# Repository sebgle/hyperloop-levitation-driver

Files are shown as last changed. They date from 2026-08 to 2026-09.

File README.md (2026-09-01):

# Hyperloop Levitation Coil Driver

A two-channel H-bridge driver for the levitation coils on a hyperloop pod. It takes PWM from the
pod's control computer and switches 60 V into two coils at up to 30 A each, roughly 1.8 kW per
coil. Two boards drive the pod's four coils.

Design work for the levitation subsystem of a student hyperloop pod. The levitation team set the
requirements. The schematic, board layout, documentation and verification scripts are mine. This
repository holds the KiCad 10 project along with the design notes, the reviews, and the scripts
that check the layout.

**Status: schematic done and verified. Placement done. Routing under way.**

## Requirements

| | |
|---|---|
| Bus | 60 V max, battery fed |
| Current | 30 A per coil by design. The team's stated minimum is 60 A across all four |
| Coil | About 2 Ω and 10 mH, unmeasured |
| PWM | 16 kHz now, 32 kHz ceiling |
| Control | PID runs on a separate MCU. This board takes PWM and a shutdown line |
| Grounding | Coils float. Only common point is the motor controller negatives |
| Rails | Pod supplies 12 V, 5 V and 3.3 V |

## The board

| | |
|---|---|
| Size | 160 × 140 mm, 4 layers, 2 oz outer / 1 oz inner |
| Parts | 184 footprints, 99 nets, 492 pads |
| FETs | 8 × IRF100B201, 100 V, 4.2 mΩ, TO-220 on a shared heatsink |
| Gate drive | 4 × IR2184, bootstrap high side |
| Sensing | 0.5 mΩ shunt in line with each coil, INA240A2 amplifier |
| Protection | ±45 A window comparator into a latch on the driver shutdown pin |
| Bus | 6 × 470 µF, ceramics at each bridge, TVS clamp |
| Connectors | Molex 38969-0002, 50 A, takes 8 AWG |

## Design decisions

### Modulation

Four transistors form an H-bridge with the coil across the middle. Which pair is switched on
decides what the coil sees.

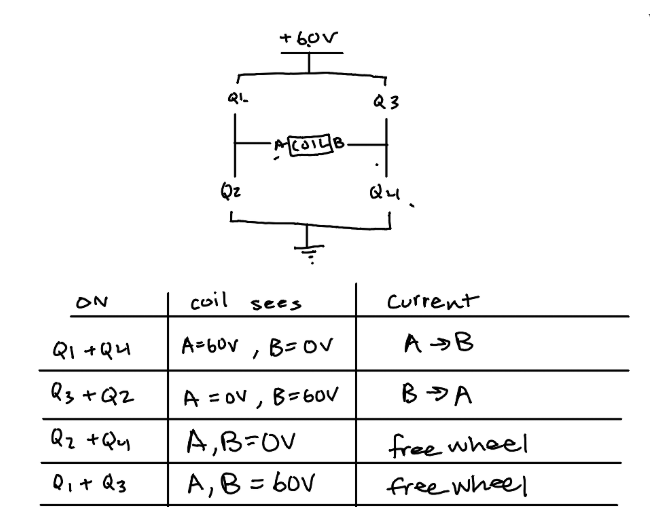
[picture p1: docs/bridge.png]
H-bridge switching states


The board cycles through these states thousands of times a second. What sets the average voltage
across the coil is which states it cycles between, and how long it holds each one.

There are two ways to pick that sequence:

```
locked antiphase   Q1+Q4 -> Q2+Q3 -> Q1+Q4 -> Q2+Q3    coil sees  +60 V, -60 V, +60 V, -60 V
unipolar           Q1+Q4 -> Q1+Q3 -> Q1+Q4 -> Q1+Q3    coil sees  +60 V,   0 V, +60 V,   0 V
```

Antiphase only uses the top two rows of the table, so the coil gets slammed between +60 V and
−60 V every cycle even when you want very little current out of it. Unipolar swaps one of those
for a freewheel row, where both ends of the coil are held at the same voltage. Nothing is
pushing the current any more, so it coasts around a loop through the two transistors and fades
slowly, the way a bike wheel spins on after you stop pedalling. A switching cycle is far too
short for it to fade much. That halves the voltage swing, and at low output the coil spends most
of each cycle coasting.

That keeps the current steadier and takes a lot of strain off the bus capacitors, which is what
decided it. A levitation coil sits near zero most of the time, so low output is its normal
operating point.

The tradeoff is that the four transistors no longer share the work evenly. Two do most of it and
run hot, two do very little and stay cool. They are arranged alternately on the heatsink so no
two hot ones sit next to each other.

### Four layers

A four-layer board costs more than a two-layer one, and the usual justification for the extra
layers, less resistance in the copper, did not apply. The power traces here are already wide
enough, and a third copper layer would save about 3 W out of 54 W.

The real reason is what sits underneath the transistors. On a four-layer board a solid ground
layer sits 0.2 mm below them instead of 1.44 mm away on the other side of the board. Current
returning through that nearby layer takes a much tighter path, which shrinks the voltage spikes
the transistors see each time they switch. The same layer shields the small measurement signals
from the 30 A being chopped a couple of centimetres away.

### Current sensing

Each coil's current is measured across a very small resistor, half a milliohm, which turns 30 A
into about 15 millivolts. An amplifier scales that up fifty times to something the rest of the
circuit can work with. The resistor sits in the wire feeding the coil rather than in the ground
return, because current in a levitation coil flows in both directions and this is the only
position that sees both. TI's application note SBOA174 covers why this amplifier suits the job.

### Overcurrent protection

If coil current passes 45 A in either direction, a comparator trips and a latch shuts the gate
drivers off and holds them off until the microcontroller clears it. Without the latch the fault
would clear itself the moment current dropped, and the board would switch on and off
repeatedly. The comparator takes 1.3 microseconds to react, which sounded far too slow until I
worked out how fast the current can actually change: the coil's inductance limits it to about
13 milliamps in that time. The genuinely fast failure is both transistors in one leg turning on
together, and the gate driver chips block that on their own.

## Checking the layout

Instead of trusting measurements written down by hand, a script reads the board file and
recalculates them. Every spacing and clearance figure quoted in the documentation comes out of
it, and it runs in about a second.

```
courtyard overlaps: 0
CH1 A   12.9 mm    CH1 B   16.7 mm
CH2 A   12.9 mm    CH2 B   16.7 mm
heatsink-shadow intrusions: none
```

The wiring was also checked against the connection list exported from the schematic, separately
from KiCad's own checker, and matched exactly on all 99 nets and 492 pads. Two rules that used
to live in a document now live in the board's rule file, so the software refuses to let me break
them: high-current nets have to be poured as wide copper areas rather than drawn as thin traces,
and the inner ground layer stays solid.

## Assumptions

Some inputs to this design were never measured, so every assumption is written down with what
happens if it turns out wrong. The full list, A1 to A16, is in `docs/09_design_sheet_rev0.md`.
Three of them matter:

- **A1**: the coil is 2 Ω. If it is really 4 Ω, the board can only push half the current and the
  high-side gate drive stops working. Nobody has put a meter on it yet.
- **A9**: 60 V is the maximum, not the normal running voltage. If it is the normal voltage, a
  full battery sits closer to 67 V and the 100 V parts get uncomfortably close to their limit.
- **A16**: the power traces are 10.7 mm wide. That figure comes from an older standard, and the
  project notes already say it should be rechecked against the current one.

## Mistakes and what they changed

**Measured the wrong thing.** Six large capacitors were supposed to fit between the two coil
connectors. Comparing the metal pads, they fit. Comparing the space each part actually needs
around it, they did not, because the connector needs far more room than its pads suggest. The
board grew from 160 × 100 to 160 × 140 mm, and I rewrote the checker to use the real keep-out
areas.

**Dropped a digit.** The board file said the copper was 0.007 mm thick instead of 0.07 mm.
Nothing inside KiCad depended on it, but it would have gone to the manufacturer, and at that
thickness the power traces would have run ten times hotter than intended.

**Trusted a number that looked deliberate.** The high-current traces were set to 3 mm wide,
which looks like a real power width. At 30 A that works out to roughly a 160 °C rise. It needed
about eight times more copper than that. The same setting had also caught ground, so all 119
ground pads inherited it.

**Reviewed in the wrong order.** Three rounds of review found 19, then 5, then 14 problems, and
about 40 % of the last round came from fixes made in the first two. Patching a design whose main
input is still unmeasured creates problems faster than review finds them, so I stopped and moved
on to layout.

## Repository layout

```
final_lev.kicad_*                KiCad project and its custom design rules
lib.pretty/                      custom connector footprint
tools/lay.py                     the layout checker
docs/00_design_log.md            running log, including the corrections
docs/01_reference_library.md     every datasheet and app note used, each one checked
docs/09_design_sheet_rev0.md     component values and the assumption list
docs/16_adversarial_review.md    38 review findings across three rounds
docs/18_firmware_interface.md    what the control microcontroller has to send
docs/20_layout_phase.md          placement and the verified clearances
docs/21_stackup_and_layers.md    layer stackup and routing order
```

## Not done

- Routing. The inner ground layer is poured, nothing else is.
- The coil has never been measured. Once it is, several numbers have to be redone together,
  because they all depend on it: ripple, transistor heating, heatsink size, gate drive supply
  and trip timing.
- Some heat calculations in `docs/09` were done under the older switching scheme.
- The bus fault detector is specified and not designed.
- `docs/09` still lists an older set of current-sense parts. The schematic is right and that
  document is stale.

## Running it

KiCad 10 on Windows. The scripts are Python 3, standard library only. From the project root:

```powershell
py tools\lay.py
```

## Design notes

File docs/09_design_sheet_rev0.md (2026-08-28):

# Design Sheet Rev 0 — Values to Draw Tonight

Levitation coil drive stage · Sebastian · 2026-08-11
**Status: provisional. Every assumption is registered in §2 with a change path.**

---

## 1. Decisions locked for this revision

| Decision | Choice | Why this one |
|---|---|---|
| **Topology** | Full H-bridge per yoke | Bidirectional confirmed (EDD Fig. 3, −16 A to +12 A) |
| **Board** | **One 2-channel board**, build two | Subset that works either way; halves bus current to 60 A; smaller layout is achievable tonight |
| **Design current** | 30 A/yoke, 15 A/coil | EDD peak, safe upper bound |
| **Design PWM** | 32 kHz (thermal worst case) | Their stated ceiling |
| **Modulation** | **Hardware-agnostic — see §3.1** | Assumption eliminated, not logged |

---

## 2. Assumption register

**This is the important artifact.** Put a copy in the schematic as a text block so it travels
with the design instead of living in your head.

| # | Assumption | Value used | Basis | Confidence | If wrong → | Change cost |
|---|---|---|---|---|---|---|
| A1 | Coil resistance | 2 Ω/coil, **1 Ω/yoke** | EDD §2.2, confirmed by independent geometry calc (250 t × 18 AWG ⇒ 1.6–2.1 Ω) | **High** | If 4 Ω: peak current halves, duty doubles to 100 %, bootstrap breaks | Rework gate drive. **Measure this first.** |
| A2 | Coil inductance | 10 mH/coil, k = 0.85, **L_yoke = 9.25 mH** | Chat recollection + my magnetic-circuit estimate (10–13 mH) | **Low** | Bus energy 2.1–5.9 J | **Nothing** — §3.2 removes the dependency |
| A3 | Modulation scheme | Unknown | — | — | — | **Nothing** — §3.1 removes the dependency |
| A4 | Logic level | 3.3 V or 5 V | Unknown | — | — | **Nothing** — §3.3 removes the dependency |
| A5 | Peak duration | **Continuous** | Deliberately conservative; EDD implies seconds | Conservative | Over-designed heatsink | None — just oversized |
| A6 | Ambient temperature | **40 °C** | Standard assumption, nobody has stated it | **Low** | Heatsink resizes linearly | Swap heatsink. Mechanical only. |
| A7 | Aux rails | Board generates its own 12 V and 3.3 V from the 60 V bus | Nobody has said the pod supplies them | Medium | If pod supplies them, DNF the regulator | **DNF one part** |
| A8 | 30 A/yoke is real | Design to 30 A | Safe upper bound whether real or inherited | Conservative | Over-designed | None |
| A9 | Bus voltage | 60 V **max** (not nominal) | EDD §2.1 states "Input Voltage (Max)" | High | If nominal, top-of-charge ~67 V → 100 V FETs get tight | Re-check FET margin |
| A10 | Board outline | **160 × 140 mm** — grew from 160 × 100 (Eurocard) on 2026-08-21 | Decided 2026-08-14 as 160 × 100, no upstream constraint stated; set by the 8× TO-220 row (~120 mm) and the §4.2 heatsink estimate (~150 × 100 mm). Grew to 140 mm tall because the six Ø16 × 31.5 mm bulk cans did not fit between the coil connectors — `20_layout_phase.md` §20.1 | Decision, not measurement | Outline changes | Re-do placement. No schematic impact. Cheapest thing here to change *before* routing, expensive after |
| A11 | Mounting | **4 × M3**, Ø3.2 mm, on a **150 × 130 mm** rectangle: H1 (105,55) H2 (255,55) H3 (105,185) H4 (255,185) | Decided 2026-08-14 as 150 × 90 when the board was 160 × 100; the holes moved with the board's growth to 160 × 140 and this entry was corrected 2026-08-24 to match the file. Nearest part 9.60 mm, edge margin 5 mm | Measured from the board, not a decision | Hole pattern moves | Move 4 holes + keepouts. Trivial before routing |
| A12 | Chassis bond | Mounting holes are `MountingHole:MountingHole_3.2mm_M3_Pad`: a **plated 3.2 mm hole with a 6.4 mm annular pad on all four copper layers**, currently carrying **no net**. Verified 2026-08-27 by reading the pad block. The 0 Ω 1206 jumper this row used to claim was specified and never drawn, and no 0 Ω part exists in the netlist, but the hole itself is a better bonding provision than that jumper would have been. The `no net found ... no pin 1 in symbol` warning on update-from-schematic is the symbol's doing: `MountingHole` has no pin, so the pad cannot inherit a net | Yokes float; the only common point is at the motor-controller negatives (`03_open_questions.md`). A bonded screw would create an unplanned 60 A return path through the pod structure, so floating is still the intended state | Medium | If chassis bonding is required | **Swap the symbol to `MountingHole_Pad` and assign the pad to GND.** Schematic edit and a re-push, no board re-spin: the copper is already there on all four layers. For a bench trial before committing, solder a wire from a GND test point to the screw (TP212 to H4 is the shortest run at 56 mm). Note for layout: because the pad has no net, every zone treats it as a foreign obstacle, which is what forces the COIL_A1 pour to keep its distance from H1 |
| A13 | Harness entry | Bus in on one short edge, coils out on the other; logic on the far long edge | Decided 2026-08-14. Follows the current path: bus → bulk → bridge → shunt → coils | Decision | Connector edges move | Re-do placement of 4 connectors and the high-current pours |
| A14 | **Modulation scheme** | **Unipolar (3-level) PWM** — leg A at D, leg B at 1−D; the two channels interleaved **90°** | Decided 2026-08-14. Bus ripple, plus linearity through zero | Decision | If locked antiphase is mandated: bus ripple 52 A rms against a ~14 A bank | **Capacitor bank moves to polymer or film.** BUS sheet respin + BOM |
| A15 | Stackup dielectrics | F.Cu→In1.Cu prepreg **0.2 mm**; core **0.97 mm**; In2.Cu→B.Cu prepreg 0.2 mm. Copper 2 oz outer / 1 oz inner, board total **1.600 mm** | Decided 2026-08-24, entered in Board Setup. Standard 1.6 mm 4-layer construction, **not** a fab’s published table — 0.97 mm is not a stocked core (0.8/0.9/1.0/1.1/1.2 are), it is the residue that makes the total land on 1.600. Reasoning in `21_stackup_and_layers.md` | Decision, not a quote | Only `dielectric 1` matters: loop inductance over the plane goes as μ₀·h/w, so a larger F.Cu→In1.Cu separation scales overshoot linearly (≈1.5 V per 10 mm of run per 1.24 mm of extra separation, at 30 A / 30 ns). Separately, JLCPCB’s **default inner copper on 4 layers is 0.5 oz**, not 1 oz — if 1 oz inner is not explicitly ordered, the In2.Cu parallel-copper saving falls from 9.30→6.20 W to 9.30→7.44 W | Replace all three dielectric rows with the fab’s actual stackup table at quote time. Board Setup edit only, no layout impact. Order 1 oz inner explicitly |
| A16 | HV net class sizing | `HV_POWER` track width **10.7 mm**, clearance **0.3 mm**, via 1.2 / 0.6. `GND` split out to `PWR_GND` (via 1.2 / 0.6); bootstrap split out to `HV_BOOT` (0.5 mm, via 0.8 / 0.4) | Decided 2026-08-24. 10.7 mm is the IPC-2221 external width for 30 A at 2 oz, ΔT = 20 °C — the class now states the sized width instead of 3.0 mm, which is ~160 °C at 30 A. 0.3 mm clearance is against IPC-2221B Table 6-1 at 51–100 V: coated external needs 0.13 mm, so 0.3 mm is 2.3×. The uncoated column (0.6 mm) applies only at pad openings, and the tightest 60 V pad pair on the board measures **0.635 mm** — the TO-220 lead pitch at Q1/Q2/Q202/Q203, 89 HV pads examined | Standard + measurement, not a guess | Conformal coating, operation above 3050 m, or a bus above 100 V all move the IPC column, and the 0.635 mm TO-220 gap becomes the binding number at 6 % margin | Net class values are a Board Setup edit. The 0.635 mm gap is set by the FET package and would need a different footprint |
| A17 | Shared bus section current | The bulk-to-bridge feed carries **both** channels, up to **60 A**. **Corrected 2026-08-27: the 28.0 mm figure in the previous version of this row was wrong**, because it applied the IPC-2221 *trace* formula to what is a *plane*. On In2.Cu at 1 oz that same formula demands **146 mm** of width, which is the whole board -- a result that says the formula is outside its validity, not that the board is impossible. A plane is counted in squares: 1 oz copper is 0.494 mOhm per square, the cap row at y=143 to the bridge row at y=62 is 81 mm across roughly 150 mm of width, so **0.54 squares = 0.267 mOhm**. Adding spreading resistance at the pads (0.026 mOhm across the six bulk caps in parallel, 0.165 mOhm at one FET drain pin) gives about **0.46 mOhm end to end: 27 mV and 1.65 W at 60 A**, spread over 150 x 80 mm, which is 0.14 mW/mm2 | Derived 2026-08-24, corrected 2026-08-27. Every width in the project until then was sized for 30 A as a trace, and the section before the bus splits was first sized the same way | Arithmetic, and the first version of it used the wrong model | The corridor width is **not** the constraint it was thought to be. In2.Cu carries the bus as a plane; every +60 V pad that carries current is through-hole (4 FET drains, 6 bulk caps, J101), so the plane reaches all of them down their own barrels with no vias in the power path. **In2.Cu still cannot be used for signal routing**, for the original reason: cutting it up would turn a plane back into traces | Re-derive if the stackup changes to 0.5 oz inner, where the sheet resistance doubles to 0.99 mOhm/square and the numbers above double with it |

**Three of the four blockers are removed by design in §3, not by assumption.** Only A1 and A2
really matter, and A2 is neutralised.

### A14 — why unipolar, in full

This is the assumption the capacitor bank rests on, so the reasoning is written out rather
than left implicit.

The coil is effectively a DC source to the bus — its own ripple is 0.15 A pk-pk against 30 A —
so whatever fraction of the period the bridge draws from the bus, it draws the *full* 30 A.
That fraction is what sets the bus RMS ripple, and it differs by a factor of three across the
three candidate schemes:

| Scheme | Bus draws for | AC ripple, 1 ch | 2 ch in phase | 2 ch interleaved (see note) |
|---|---|---:|---:|---:|
| Locked antiphase | the whole period, sign-reversing | 25.98 A | **51.96 A** | 30.0 A |
| Sign-magnitude | D = 0.5 | 15.00 A | 30.0 A | ≈ 0 |
| **Unipolar (3-level)** | \|2D−1\| = 0.5 | **15.00 A** | 30.0 A | **≈ 0** |

Six Rubycon ZLH cans give roughly **14 A**. Locked antiphase is off the table on that alone.

Between the other two, the deciding factor is **behaviour at zero current, not ripple** —
they are identical on ripple. HEMS force goes as (B_pm ± B_coil)², so with the magnets
carrying static weight the coil current trims about zero and crosses it routinely.
Sign-magnitude cannot cross zero continuously: the direction leg has to flip, which puts a
deadband and a discontinuity exactly at the operating point the loop lives at. Unipolar is
linear through zero — D = 0.5 means zero volts, zero coil current, and **zero bus draw**.

Unipolar also halves the coil's own ripple and doubles its frequency, because the coil sees
+V / 0 / −V at 2·f_sw.

**THE INTERLEAVE ANGLE IS 90°, NOT 180° — corrected 2026-08-14 night.** Under unipolar the
bus draws current only while Q1 and Q4 are both on, which happens **twice per carrier
period**, so the bus-ripple fundamental is at 2·f_sw. A 180° carrier shift is a full 360° of
that fundamental and cancels **nothing** — it is bit-identical to running the two channels in
phase. Verified numerically:

| | in phase | 180° | 90° |
|---|---:|---:|---:|
| ripple at D = 0.75 | 30.0 A | **30.0 A** | **0.1 A** |
| ripple at D = 0.875 | 26.0 A | 26.0 A | 15.0 A |
| bank capability | | | 14.1 A |

The 180° figure was carried over from the locked-antiphase analysis, where the ripple
fundamental *is* at f_sw and 180° genuinely cancels. It does not transfer. At 180° the bank
would have run at 2.1× its ripple rating.

Note the D = 0.875 row: even at 90° the bank is marginal at high duty. Either the duty needs
a clamp or the bank needs more cans — resolve when the coil is measured.

**Cost, stated honestly.** Dead time now distorts both legs rather than one, so there is a
small duty-dependent error near zero that firmware may need to compensate. That is a
calibration, not a topology problem. And the 90° interleave has to be real — if both
channels share a carrier with no phase offset, the bus ripple doubles to 30 A and the bank is
marginal again. **The interleave is a hard requirement of this assumption, not an
optimisation.**

**What this supersedes.** `16_adversarial_review.md` §5 recommended sign-magnitude. That was
right about locked antiphase being unaffordable and wrong to stop there — it optimised for
bus ripple alone and did not check the zero-crossing behaviour against the PM-biased
operating point. Unipolar gives the same ripple without the deadband.

**What still needs doing.** `09_design_sheet_rev0.md` §4.1 sizes the FET losses under
"Antiphase (design to this)". Those numbers need re-deriving for unipolar before the thermal
design is final — switching loss should fall, because each leg hard-switches less often.

---

## 3. Design moves that make assumptions not matter

### 3.1 Two independent PWM inputs per channel — kills the modulation-scheme blocker

Instead of building a logic block that converts PWM+DIR into gate signals, **bring one PWM
input per half-bridge straight to the connector.** Two PWM lines per yoke, plus one shared
shutdown.

The IR2184 already provides deadtime and shoot-through interlock internally, so each
half-bridge is safe driven from a single logic input. That means:

- **Sign-magnitude:** firmware PWMs one leg, holds the other static
- **Locked antiphase:** firmware drives both complementarily
- **Independent/mixed decay:** also available

All three in firmware, **zero hardware change**. The question I couldn't get answered stops
mattering. Cost: one extra signal wire per channel.

Per channel: `PWM_A`, `PWM_B`, `/SD`, `ISENSE_OUT`, `/FAULT`, `AGND`, `DGND`.

### 3.2 Slow-decay-on-fault — kills the bus energy-dump problem

At 30 A the yoke stores 4.2 J (up to 5.9 J at worst-case L). Dumped into bus capacitance with
the battery absent, the bus reaches **146–169 V** against 100 V parts. Capacitance cannot fix
this — even 1000 µF only gets you to 109–124 V.

**The fix is a rule, not a component.** On bus fault (undervoltage or overvoltage detected),
turn **both low-side FETs on** instead of tri-stating. The coil current then circulates
`coil → Q2 → Q4 → coil` and its energy dissipates in the coil's own 1 Ω:

    τ = L_yoke / (R_coil + 2·R_ds(on)) = 9.1–12.8 ms → fully decayed in 46–64 ms

**All 4.2 J stays in the coil. The bus never sees it.** Costs nothing but a comparator and a
local hold-up capacitor on the 12 V gate-drive rail so the FETs can still be driven for those
~60 ms.

This also makes A2 (inductance) irrelevant to the protection design — which is why the one
assumption I have least confidence in stops being a risk.

*This is what the original design's "let the coil freewheel rather than actively reverse"
instinct was reaching for. It just wasn't extended to the fault case.*

### 3.3 Schmitt-buffer the control inputs — kills the logic-level blocker

**74LVC2G17** (dual Schmitt buffer) on each channel's PWM inputs, supplied from the local
3.3 V rail. Inputs are 5 V-tolerant, so 3.3 V and 5 V MCUs both work with no change. Also
cleans up edges on a long noisy harness.

*Upgrade path:* if inter-board ground offset becomes a problem (I flagged it — the INA240
outputs sit on grounds carrying 30–60 A of switching current), swap to a digital isolator
(ISO7721 / Si8621). **Lay the footprint out to accept either** and you keep that option free.

### 3.4 Design thermals for the worst modulation

Antiphase switches all four FETs; sign-magnitude switches two. Size the heatsink for
antiphase at 32 kHz and you are safe under any answer. Costs a bigger heatsink, which is the
cheapest possible insurance.

---

## 4. Component values — ready to draw

### 4.1 Power stage (per channel)

| Item | Value | Note |
|---|---|---|
| Q1–Q4 | **IRF100B201** TO-220AB | 100 V, 4.2 mΩ max, Q_g 255 nC max, R_thJC 0.34 °C/W |
| Bus bulk | 2× **470 µF 100 V** electrolytic | Normal ripple; the fault case is handled by §3.2 |
| Bus ceramic | 4× **1 µF 100 V** 1210 + 4× **100 nF** 0805 | Right at the bridge, tight loop |
| Bus TVS | **5.0SMDJ70A** | V_R 70 V, V_BR 77.8–86 V. Residual clamp only |

**Losses at 30 A, 125 °C junction, R_ds(on) = 6.72 mΩ hot:**

| | Sign-magnitude | Antiphase (design to this) |
|---|---:|---:|
| Conduction, per channel | 12.1 W | 12.1 W |
| Switching @32 kHz, per switching FET | 3.70 W | 3.70 W |
| **Channel total** | 19.5 W | **26.9 W** |
| **Board total (2 ch)** | 39.0 W | **53.8 W** |
| Worst single FET | 6.73 W | 6.73 W |

### 4.2 Heatsink

    R_th(s-a) ≤ 1.35 °C/W

Derived at T_a = 40 °C, T_j = 125 °C, TIM = 1.5 °C/W (silpad), 53.8 W board, 6.73 W worst FET.

⚠️ **1.35 °C/W in natural convection needs a substantial extrusion** — roughly 150 × 100 mm
with 40 mm fins. With any forced air it becomes easy. **This is why ambient temperature and
airflow (question C20) matter** — it is the one open question that directly affects a
mechanical part you have to buy.

### 4.3 Gate drive (per channel: 2× IR2184)

| Item | Value | Basis |
|---|---|---|
| C_boot | **1 µF X7R 25 V** | Q_tot ≈ 405 nC → **0.41 V droop**. Budget is 1.5 V (11.3 V start − 9.8 V UVLO max) |
| R_boot | **1 Ω** | Gives **D_max = 94 %** at 16 kHz. At the 50 % design point this is enormous margin |
| D_boot | **ES1D** 200 V ultrafast | Must block the full bus |
| R_gate on | **10 Ω** | → I_g 0.70 A, t_sw 64 ns |
| R_gate off | **4.7 Ω** + parallel diode | Faster turn-off, protects against dv/dt-induced turn-on |
| Deadtime | IR2184 internal ~500 ns | Adequate against ~200 ns turn-off. Do not defeat it |
| VCC decoupling | 1 µF + 100 nF at each driver | |

### 4.4 Current sense (per channel)

| Item | Value | Basis |
|---|---|---|
| Shunt | **1 mΩ, 4-terminal, ≥2 W** | 0.90 W at 30 A. Use a metal-element 4-terminal part, not a 2512 thick film |
| Amp | **INA240A1** (gain 20) | 30 A → 600 mV. Full scale **±82 A**. 1 A → 20 mV |
| Reference | **1.65 V** from the 3.3 V rail | Bidirectional, centred |
| Placement | **In-line with the coil** | Only placement that sees true bidirectional coil current. This is what the INA240's PWM rejection exists for — TI SBOA174 Table 2 |
| Input filter | RC, corner ≫ control bandwidth | Set generously; tune once question B10 is answered |

### 4.5 Over-current protection (per channel)

| Item | Value | Basis |
|---|---|---|
| Threshold | **±45 A** | 30 A legitimate, 60 A ceiling |
| Comparator | **LM393** (dual = window comparator) | Trips at **2.55 V** and **0.75 V** against the 1.65 V ref |
| Latch | **74HC74** set-dominant, drives `/SD` low | ⚠️ The old BOM had no latch. Without one the fault self-clears and chatters |
| Reset | MCU line or power cycle | |

**Why LM393 is fine here** — its 1.3 µs propagation delay looked slow, so I checked it:
worst-case di/dt is (60 V + 30 V)/9.25 mH = 9730 A/s. In 1.3 µs the current rises **12.6 mA**.
The load inductance protects you. The fast fault is shoot-through, and the IR2184's interlock
handles that.

### 4.6 Aux rails

| Item | Value | Note |
|---|---|---|
| 60 V → 12 V | **LM5164** (100 V, 1 A synchronous buck) | Powers gate drivers. Needs ~100 mA |
| 12 V hold-up | **220 µF** local | **Required for §3.2** — the FETs must stay driven for ~60 ms after bus loss |
| 12 V → 3.3 V | Small LDO | INA240 supply, 1.65 V reference, Schmitt buffers |

*If the pod supplies 12 V and 3.3 V (question B17), DNF the LM5164 and feed the rails
directly. One part.*

### 4.7 Connectors — **and the answer for your lead**

| Connection | Part | Rating |
|---|---|---|
| **Yoke output**, battery in | **Molex 38969-0002** | **50 A, 600 V, 20–8 AWG**, 12.7 mm pitch, 2 position, PCB mount |
| Signals | Molex 0389220002 (the lead's part) | 20 A, 300 V, 12–26 AWG — fine for logic |

**This is the pitch to your lead:** same manufacturer, same barrier-strip style, PCB mount —
but **50 A and it accepts the 10 AWG the EDD specifies**. It satisfies the intent of the
constraint while meeting the actual requirement. The 20 A part stays on the signal side where
it is entirely appropriate.

---

## 5. For the LTspice build

Parameterise the two things you don't know, so a corrected measurement is a one-line change:

```
.param Rcoil=2      ; ohm per coil      -- A1, EDD, med-high confidence
.param Lcoil=10m    ; H per coil        -- A2, ESTIMATED, low confidence
.param kcpl=0.85    ; coupling          -- A2, ESTIMATED, low confidence
.param Vbus=60
.param Fpwm=32k
```

**Sweep, don't confirm.** Run `.step param Lcoil list 5m 10m 13m` and look at what actually
moves. That tells you how sensitive the design is — which is real information. Running one
sim at an assumed value and calling it verified is the previous revision's mistake.

Worth simulating tonight, in priority order:

1. **Bootstrap hold-up** across the duty range — confirms §4.3
2. **Slow-decay-on-fault** — force the bus open at 30 A and confirm the bus stays under 100 V
3. **Current ripple** vs. modulation scheme — antiphase ripple is much worse than
   sign-magnitude and this is where you'd see it
4. **OCP trip timing** into a shorted coil

---

## 6. When the answers land

| Answer | What changes |
|---|---|
| A1 = 4 Ω, not 2 Ω | **Significant.** Peak current halves, duty → 100 %, bootstrap needs a charge pump. Rework gate drive |
| A2 measured L | Nothing structural — §3.2 removed the dependency. Update the sim and the ripple numbers |
| A3 modulation | **Nothing** — §3.1 covers all cases |
| A4 logic level | **Nothing** — §3.3 covers both |
| A6 ambient ≠ 40 °C | Swap the heatsink. Mechanical only |
| B11 two-yoke flight | Board count only. Schematic unchanged |

**A1 is the one that hurts.** It is also the one with the highest confidence and the easiest
measurement. If you get one number from the lev team, get that one.

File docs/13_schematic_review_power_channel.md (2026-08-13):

# Schematic Review — `power_channel` sheet

Levitation coil drive stage · Sebastian · rev 1, 2026-08-13
Reviewed against `09_design_sheet_rev0.md`.

> **Rev 1 corrects rev 0's headline finding.** Rev 0 reported the LM393 as powered
> backwards. It is not. See §1 for the retraction and the root cause. Everything from
> §2 onward is unchanged.

**Method — read this first.** I did not eyeball the screenshot. I read the actual
`.kicad_sch` file, rebuilt the connection graph from the raw geometry (symbol origins,
library pin offsets, KiCad's rotation/mirror transforms, wire segments, junctions,
labels, power symbols) and extracted the netlist myself. Every claim below is a
statement about the file, not about a picture of it. Where I could not resolve
something from the file alone, I say so.

Sheet contents: **54 components** (23 C, 19 R, 4 Q, 3 D, 5 U) + 32 power symbols,
142 wires, 57 junctions, 36 labels, 2 no-connect flags, A3 paper.

---

## 0. Geometric hygiene — clean

These are the errors that normally hide in a hand-drawn sheet. The file has none of them:

| Check | Result |
|---|---|
| Wire endpoints ending in mid-air | **none** |
| Labels sitting on nothing | **none** |
| Wires crossing without a junction where one is needed | **none** |
| Wires crossing *with* an unintended junction | **none** |
| Component pins not touching anything | only U5.8 / U5.9, both correctly flagged no-connect |
| Power symbols attached to nothing | **none** |
| Duplicate / overlapping wire segments | none |

Every net resolves. That is a genuinely clean drawing job for 142 wires.

---

## 1. RETRACTED — the LM393 supply is correct

**The first issue of this document claimed U4 was powered backwards. That was wrong.
Sebastian caught it. There is no blocking error on this sheet.**

Correct netlist: **U4 pin 8 (V+) → `+5V`. U4 pin 4 (V−) → `GND`.**

### What I got wrong, and why it matters for the rest of this document

Everything here is reconstructed from raw geometry, which means it all rests on getting
KiCad's rotation matrices right. For a symbol placed at `(at x y 90)` the mapping from
library coordinates to sheet coordinates is one 2×2 matrix, and I solved for it
empirically by testing candidates against the file and keeping the one that made pins
land on wires.

I tested the wrong pair. The two candidates I compared were:

    (0, 1, 1, 0)    det = −1     ← legal
    (0, 1, −1, 0)   det = +1     ← NOT legal for an unmirrored symbol

and picked the second because it made U4's pins land on the +5 V wire and the GND symbol
while the first left them floating. That was real evidence and it pointed at a
physically impossible transform.

**The constraint I skipped:** every unmirrored symbol placement in KiCad is the default
transform `(1, 0, 0, −1)` — determinant −1, because library Y is up and sheet Y is down —
composed with a pure rotation, determinant +1. The product must have **determinant −1**.
A determinant +1 matrix is a *mirrored* placement, and the file says plainly that U4 has
no mirror. That one check eliminates my answer in a single line.

The two legal candidates for the 90° family are `(0, 1, 1, 0)` and `(0, −1, −1, 0)`. I
never tested the second, because I had it filed under 270°. It is the right one:

    90°  → (0, −1, −1, 0)        270° → (0, 1, 1, 0)

Under the correct matrix, U4 unit 3's pins land at y = 59.69 with **V+ at x = 128.27**
(the +5 V wire) and **V− at x = 143.51** (the GND symbol). Which is what the schematic
looks like on screen, which is what Sebastian said.

**The process failure, stated plainly:** I treated "which hypothesis makes more pins land
on wires" as decisive without first checking whether the hypothesis was admissible.
Landing on wires is *evidence*. The determinant is a *constraint*. Constraints get
applied first — they are free, and they delete whole branches before you start weighing
evidence.

And note the shape of the failure, because `08_honest_assessment.md` already named it:
*a design that is internally consistent and externally wrong passes every check you can
run on it.* This time it was the analysis, not the design. My reconstruction was fully
self-consistent under a transform that cannot physically exist, and it stayed
self-consistent right up until someone looked at the actual screen.

### What this retraction does and does not touch

Re-running the extraction with the corrected matrices changes the netlist in exactly one
substantive place — U4's two supply pins. Every other difference is a pin-number swap on
a symmetric two-terminal part (resistors, non-polarised capacitors), where net
*membership* is identical and only the 1/2 labelling flips. Verified by diff.

**The only polarised parts at 90° or 270° are U4 unit 3 and D2.** D2 re-checks correct:
cathode on `+60V`, anode on `GND`. But given the above, please confirm it with your eyes
rather than my arithmetic — **the cathode bar (the flat line with the little Z-ticks
on the ends) should be at the top, against the +60 V rail, with the triangle pointing up
into it.** If it looks the other way round, tell me.

Everything in §2 onward is independent of the rotation question and stands unchanged.

---

## 2. The protection chain is correct

I traced it pin by pin and it does what it is supposed to do.

**LM393 supply** — U4 pin 8 (V+) → +5V, pin 4 (V−) → GND, decoupled by C21 100 nF across
the same two rails. **Correct.**

**Threshold divider** — R14 10k (+3.3V→VTH_HI), R15 24k (VTH_HI→VTH_LO), R16 10k
(VTH_LO→GND).

    VTH_HI = 3.3 × 34/44 = 2.550 V
    VTH_LO = 3.3 × 10/44 = 0.750 V
    trip    = (2.55 − 1.65) / (20 × 1 mΩ) = ±45 A      ✓ matches §4.5

Both thresholds and the INA240's 1.65 V mid-scale derive from the *same* 3.3 V rail, so
the trip point is ratiometric — rail error cancels instead of shifting the trip. That is
a real property of the way you drew it and worth saying out loud in the writeup.

**Comparator polarity** — U4A: `+` = VTH_HI, `−` = ISNS → output pulls low when ISNS
climbs above 2.55 V. U4B: `+` = ISNS, `−` = VTH_LO → output pulls low when ISNS falls
below 0.75 V. Both open-drain outputs (pins 1, 7) tie to `FAULT_N` with R17 10k to +5 V.
Crossed inputs give you OR, not AND. **Correct.**

**Latch** — U5A: pin 4 (S̄/PRE) ← FAULT_N, pin 1 (R̄/CLR) ← RESET node, pins 2 & 3
(D, CLK) → GND, pin 5 (Q) → FAULT, **pin 6 (Q̄) → SD**. Power-on: C22 holds R̄ low,
Q = 0, Q̄ = 1, SD high, drivers enabled. Fault: S̄ low → Q = 1 (FAULT out), Q̄ = 0 →
SD low → shutdown. Set-dominant, powers up in the no-fault state. **Correct.**

**U5B tied off** — pins 10 (S̄) and 13 (R̄) to +5V, pins 11 (C) and 12 (D) to GND,
pins 8 and 9 no-connect. **Correct** — unused outputs left open, unused inputs tied,
which is the right way round.

**R19** 10k from SD to GND: if the latch loses power, SD is pulled low and the bridge
shuts down. Fail-safe in the correct direction. **Correct.**

**INA240** — IN− (1) ← R13 ← COIL_A, IN+ (8) ← R12 ← SW_A, OUT (5) → ISNS, VS (6) →
+3.3V with C20 100 nF, GND (2) → GND, REF1 (7) → GND, REF2 (3) → +3.3V. Verified against
TI SBOS662: pin 4 is "Reserved. Connect to ground or leave floating" — you tied it to
GND, which the datasheet explicitly permits. (My earlier sketch said "leave open"; both
are legal, no change needed.)

Current sign: sourcing current leaves SW_A, crosses the shunt, enters COIL_A, so
V(SW_A) > V(COIL_A) → IN+ > IN− → ISNS rises above 1.65 V. Positive coil current reads
high, which is what the +45 A threshold assumes. **Correct.**

**Bus TVS D2** — cathode on +60V, anode on GND. **Correct.** (I re-derived the 270°
rotation from scratch to check this one; it comes out right.)

**Electrolytics C9/C10** — pin 1 (+) on +60V. **Correct.**

**Bootstraps** — U1: +12V → R5 (1Ω) → D1 (ES1D, anode from R5, cathode to VB) → VB(8),
C4 1 µF across VB–SW_A. U2: identical with R8/D3/C16. Diode orientation correct in both.

**Gate loop** — R1/R2/R9/R10 10 Ω 1206 in series with each gate; R3/R4/R6/R7 10k
pulldowns, each returned to *its own* source (SW_A / GND / SW_B / GND), not to a common
node. **Correct** — this is the detail most people get wrong.

**Bridge** — Q1/Q3 drains on +60V, Q2/Q4 sources on GND, SW_A = Q1.S/Q2.D, SW_B =
Q3.S/Q4.D. Shunt R11 in series between SW_A and COIL_A; COIL_B taken directly off SW_B.
The shunt therefore carries true coil current. **Correct.**

---

## 3. Design-level findings — these are about the design, not the drawing

### 3.1 The bulk capacitors cannot carry the ripple current — quantified

This has been on the open-risk list unquantified. Here is the number.

At the 30 A design point with D ≈ 0.5:

    I_rms(bus) = I_load × √(D(1−D)) = 30 × 0.5 = 15 A RMS per channel

How that 15 A splits between the ceramics and the electrolytics, at 32 kHz:

    8 × 1 µF ceramic:        Z ≈ 1/(2π·32k·8µ)   ≈ 620 mΩ
    2 × 470 µF electrolytic: Z ≈ ESR ≈ 25 mΩ  (two 50 mΩ parts in parallel)

The electrolytics are ~25× lower impedance, so **they take essentially all of it —
roughly 14 A RMS into a pair of parts rated about 2 A RMS each.** They will run hot,
dry out, and fail. The ceramics do not rescue this: to move the split you would need
the ceramic bank below 25 mΩ at 32 kHz, which is ~190 µF of 100 V ceramic before DC-bias
derating. Not buildable.

**Options, cheapest first:**

1. **More electrolytics** — 6× 470 µF/100 V standard radial gets you to ~16 A. Six 18 mm
   cans is a lot of board area.
2. **Polymer or hybrid aluminium** — 3–4× 470 µF/100 V polymer at 3–4 A RMS each. Fewer
   parts, much lower ESR, more expensive. This is what I would do.
3. **Lower the design current** — if the real continuous number turns out well below
   30 A (still an open question with the lev team), the problem shrinks as I².

**What does *not* fix it:** interleaving the two channels 180° out of phase cancels
ripple on the *shared* bus/battery side, but each channel's local commutation loop still
circulates its own ripple through its own nearest caps. Interleaving is worth doing —
it's free in firmware — but do not size the caps on the assumption it will hold.

The schematic topology does not change either way. Add two more C_Polarized symbols now
if you want the footprints, and settle the part at procurement.

### 3.2 The over-current path does the one thing §3.2 of the design sheet forbids

`09_design_sheet_rev0.md` §3.2 is explicit: on a fault, turn **both low-side FETs on**
rather than tri-stating, so the coil dumps into its own resistance and the bus never sees
the energy.

The OCP you have drawn pulls `SD` low, which tri-states both half-bridges. That is a hard
turn-off. The coil current then freewheels through the FET body diodes into the +60 V bus:

    E = ½ · L_yoke · I²  = ½ × 9.25 mH × 45²  = 9.4 J
    into 940 µF from 60 V:  V = √(60² + 2E/C) = 153 V   against 100 V parts

**When this matters:** only if the bus is isolated at the moment of the trip — battery
disconnected, fuse open, contactor open. With the battery present it absorbs the energy
and the bus barely moves, which is the normal case.

**Why I am flagging it anyway:** an over-current is a plausible *cause* of a blown fuse.
The two conditions are correlated, not independent, so "compound failure, ignore it" is
not quite right.

**Two ways forward, pick one and log it:**

- **(a) Accept for rev0.** Log it as a known limitation: OCP hard-off is safe only with
  the bus connected. Zero cost, zero schedule impact. Defensible for a first article.
- **(b) Gate the PWM inputs instead of SD.** Route `PWM_A` / `PWM_B` through a 2-input
  AND (one 74HC08, or two 74HC1G08) with the latch's Q̄. On fault, PWM goes low → the
  IR2184 turns its **low side on** → the coil circulates through Q2 and Q4 → slow decay,
  exactly §3.2, with `SD` left high. Cost: one logic part per board and the 12 V hold-up
  cap you already specified in §4.6. This also makes the OCP path and the bus-fault path
  behave identically, which is worth something on its own.

I would take (b) if you have an hour, (a) if you do not. Either is defensible; silently
having (a) while the design sheet claims (b) is not.

### 3.3 The turn-off diode from §4.3 is missing

Design sheet §4.3 specifies **R_gate on 10 Ω, R_gate off 4.7 Ω + parallel diode**. The
schematic has a single 10 Ω resistor per gate and no turn-off path.

In an H-bridge, when one FET turns on the opposite switch node slews fast and Miller
current through C_gd of the *off* FET tries to pull its gate up. A slow, symmetric
turn-off makes that worse. The asymmetric network is cheap insurance: one small-signal
diode (BAV21 / 1N4148W) and one 4.7 Ω resistor across each 10 Ω.

Four gates × 2 parts = 8 extra parts. Either add them or delete the line from §4.3 —
right now the design sheet and the schematic disagree, and that is exactly the kind of
drift that makes a design document worthless later.

### 3.4 The shunt is the 2512 thick film the design sheet told you not to use

`R11` footprint is `R_2512_6332Metric`. §4.5 says "1 mΩ, 4-terminal, ≥2 W. Use a
metal-element 4-terminal part, **not a 2512 thick film**."

At 45 A the shunt dissipates 2.0 W. A standard 2512 is 1 W. And a thick-film 1 mΩ has a
TCR in the hundreds of ppm/°C, so the trip point walks with temperature.

This was logged as a deliberate compromise, so it is not new — but the footprint is now
committed in the file, and swapping to a 4-terminal part later is a layout change, not a
BOM change. Metal-element parts that fit a 2512-class outline exist (Vishay WSLP2512,
Bourns CSS2H-2512 — 2 W and 3 W versions, ~50 ppm/°C). If you keep 2 terminals, at least
move to a metal-element part now so only the Kelvin question stays open.

### 3.5 The INA240 input filter is not filtering anything

R12 = R13 = 10 Ω, C19 = 1 nF differential.

    f_c = 1/(2π · (R12+R13) · C19) = 1/(2π · 20 · 1n) = 7.96 MHz

That is three decades above anything on this board. It is not wrong — TI's own guidance
(SBOA174) is that the INA240 is *designed* to reject the common-mode step and that heavy
input filtering degrades the CMRR balance it depends on — but you should know that this
network is doing essentially nothing, and say so, rather than have someone assume it is
a 20 kHz filter.

If you want real filtering, put it **after** the INA240 on ISNS, where a resistor costs
you nothing in gain error.

### 3.6 No bus bleed resistor

940 µF at 60 V is **1.7 J** with no discharge path. On a hand-assembled board that people
will probe, that is a shock and short hazard that persists after power-down.

Add one resistor from +60V to GND: 22 kΩ, 0.16 W steady (use a 0.5 W or two 11 k in
series for voltage rating), discharges to under 10 V in about a minute. Cheap, and it is
the kind of thing a reviewer notices immediately.

### 3.7 Single GND

§3.1 of the design sheet lists `AGND` and `DGND` separately at the connector. The
schematic has one `GND`. For rev0 this is defensible — one net, one star point, handled
in layout — but it is a decision, so log it. The INA240 output and the comparator
thresholds both reference this ground while it carries 30–60 A of switched current.

---

## 4. Fix before you run ERC

| # | Item | Action |
|---|---|---|
| 1 | ~~U4 power reversed~~ | **Retracted — see §1. Nothing to fix.** |
| 2 | Missing footprints | `U5` (74HC74), `C19`, `C20`, `R12`, `R13` have no footprint assigned |
| 3 | Hierarchical label shapes | All 7 are `input`. `COIL_A`, `COIL_B` should be `passive` (or `bidirectional`), `ISNS` and `FAULT` should be `output`. As drawn, the parent sheet will throw "input pin not driven" on nets that are actually outputs |
| 4 | Value string consistency | `100 nF` (C2, C17) vs `100nF` (C3, C11, C21, C22, C23) — splits your BOM into two lines. Pick one |
| 5 | `R11` value `1mR` | Ambiguous in a BOM. Use `0R001` or `1m` |
| 6 | Bootstrap cap mismatch | C4 is 1210, C16 is 0805 — same function, same part. Make both 0805 |
| 7 | No voltage rating anywhere | **The most dangerous BOM omission on a 60 V board.** Add a `Voltage` field to every capacitor. C3/C11 (100 nF, 0805) on the bus need ≥100 V. C9/C10 need ≥100 V |
| 8 | Tolerance field | R14/R15/R16 set the trip point — add `Tolerance = 1%` so procurement cannot substitute 5% |
| 9 | Title block | Empty. Fill in title, rev, date, your name |
| 10 | MPN coverage | 9 of 54 parts have an MPN field |

Items 2–10 stand. Note that with the U4 finding retracted, the "power input pin not
driven" errors ERC will raise on `+5V`, `+3.3V`, `+12V`, `+60V` and `GND` are now
*purely* the expected missing-PWR_FLAG messages, with nothing hiding inside them.

**ERC messages you should expect and should NOT "fix" on this sheet:**

- *Power input pin not driven* on `+60V`, `+12V`, `+5V`, `+3.3V`, `GND` — correct. Those
  rails are generated on `AUX_RAILS`, which does not exist yet. The PWR_FLAGs belong
  there, not here. Do not sprinkle PWR_FLAGs on this sheet to silence them.
- Possible *"net has more than one name"* on the SW_B / COIL_B node. That node genuinely
  is both — half-bridge B's switch node *is* the coil B terminal, because the shunt is
  only in the A leg. Intentional.

---

## 5. Verify this one thing about the +60 V net

`#PWR01` is the `power:+12V` library symbol with its **Value** field edited to `+60V`.

In this file every power symbol's library pin is unnamed, which means KiCad takes the net
name from the Value field — so `+60V` should be a distinct net from `+12V`. The netlist I
extracted agrees: `+60V` contains only the bridge drains and the bus bank; `+12V` contains
only the two driver VCC pins.

But confirm it in KiCad rather than taking my word for it, because the failure mode is
catastrophic — if those two merged, 60 V lands on the IR2184 VCC pins. **Hover the +60 V
rail and the +12 V rail and read the net names off the status bar.** Ten seconds.

---

## 6. File hygiene — fix this before you do anything else

Your project is at `Desktop\final_lev\`. The root sheet's `Sheetfile` property reads:

    ..\..\Downloads\power_channel.kicad_sch

**Your live schematic is in your Downloads folder, outside the project.** And there are
two stale decoys sitting *inside* `final_lev\`:

| File | Symbols | Status |
|---|---|---|
| `Downloads\power_channel.kicad_sch` | 58 | **live — this is your work** |
| `final_lev\power_channel.kicad_sch` | 37 | stale (no INA240, no LM393, no 74HC74, no shunt) |
| `final_lev\copy_power_channel.kicad_sch` | 24 | older still (bridge + drivers only) |

Downloads is the folder people clean out. And the two decoys are one mis-click from being
loaded and quietly losing you a day.

**Procedure — do it in this order:**

1. Close KiCad completely (there is a `~final_lev.kicad_sch.lck` right now).
2. Move `final_lev\power_channel.kicad_sch` and `final_lev\copy_power_channel.kicad_sch`
   somewhere out of the project — an `_old\` subfolder is fine.
3. Copy `Downloads\power_channel.kicad_sch` into `final_lev\`.
4. Open `final_lev.kicad_sch`, right-click the sheet symbol → Properties → set the sheet
   file to `power_channel.kicad_sch` (no path).
5. Open the sheet and confirm you see the INA240, the LM393 and the 74HC74. If you see a
   bare H-bridge, you loaded a decoy — back out and try again.
6. Then put the whole `final_lev` folder under git, or at least next to `levpdu`.

I can run steps 2 and 3 for you once KiCad is closed — say the word.

---

## 7. Summary

**No blocking errors.** The originally-reported LM393 supply reversal was my mistake and
is retracted in §1, with the root cause written up there because the root cause is more
useful than the finding was.

What remains:

- One quantified component problem — bus electrolytic ripple current, ~7× over rating (§3.1)
- One architectural decision to make explicitly rather than by accident — OCP hard-off
  vs. slow decay (§3.2)
- Two design-sheet items that did not make it into the drawing — gate turn-off diode,
  shunt type (§3.3, §3.4)
- Four smaller design notes (§3.5–3.7)
- Nine housekeeping items before ERC (§4)

The drawing itself — 142 wires, 57 junctions, 54 parts, no dangling ends, no missing
junctions, no stray labels, no floating power symbols, every polarity correct — is clean.
The real work left on this sheet is component selection and two documented decisions, not
correction.

---

## 8. Revision history

| Rev | Date | Change |
|---|---|---|
| 0 | 2026-08-12 | First issue |
| 1 | 2026-08-13 | **§1 retracted.** LM393 supply is correct; the reported reversal was an error in my geometric reconstruction (wrong rotation matrix, determinant +1, physically inadmissible). Caught by Sebastian from the schematic on screen. Netlist re-extracted with corrected matrices; one substantive change (U4 pins 4/8), all other deltas are pin-number swaps on symmetric parts. D2 polarity re-verified. §§2–6 unaffected. |

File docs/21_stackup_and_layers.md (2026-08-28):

# 21 — Stackup: copper weight, layer count, and why

**Decision date:** 2026-08-24
**Status:** decided and recorded. **Board Setup not yet reconfigured** — see §21.6.

---

## 21.1 A stackup bug found first

The board file carried **0.007 mm** copper on F.Cu and B.Cu. `14_power_channel_closeout.md`
records the intent as "copper 0.035 → 0.07 mm (2 oz)", so this was a dropped digit, not a
decision — 0.007 mm is not a copper weight that exists. Board total read 1.474 mm; with 0.07 it
comes to exactly 1.600 mm, which is what the design was aiming at.

It affects nothing already done — KiCad does not compute ampacity, so no DRC or clearance
result depended on it — but it propagates into fab outputs, and a fabricator reading the
stackup literally could have quoted 0.2 oz. At 0.007 mm the coil pours would have dissipated
**ten times** the intended power.

**Fixed** 2026-08-24 by direct file patch (KiCad closed): F.Cu and B.Cu → 0.07 mm, board total
1.474 → 1.600 mm. Core left at 1.44 mm.

> A first attempt at this patch also changed the core to 1.46 mm, which would have made the
> total 1.62 mm. Caught in the script's own printed output and reverted in the same session.
> The lesson is the cheap one: have the script print the number it computed, not just the
> number it wrote.

### What the copper is worth

```
sheet resistance (mohm/square)        20 C     70 C     85 C
  0.007 mm  (as the file had it)     2.463    2.947    3.092
  1 oz   (0.035 mm)                  0.493    0.589    0.618
  2 oz   (0.070 mm)                  0.246    0.295    0.309
  3 oz   (0.105 mm)                  0.164    0.196    0.206
```

---

## 21.2 The copper-loss picture

Coil-path loss at 30 A, on the 10.7 mm pours already placed, 2 oz, at 85 °C:

```
CH1 shunt -> J203    91.7 mm   8.57 sq   2.65 mohm   2.38 W
CH1 SW_B  -> J203    92.0 mm   8.60 sq   2.66 mohm   2.39 W
CH2 shunt -> J204    78.0 mm   7.29 sq   2.25 mohm   2.03 W
CH2 SW_B  -> J204    95.9 mm   8.96 sq   2.77 mohm   2.49 W
                                              TOTAL   9.30 W
```

With a via-stitched second copper layer in parallel:

```
+1 oz inner  (typical 4-layer)   6.20 W    saves 3.10 W   (33%)
+2 oz inner  (heavy 4-layer)     4.65 W    saves 4.65 W   (50%)
```

### The pour width is already correct

IPC-2221 external-layer sizing for 30 A at 2 oz:

```
dT = 10 C  ->  16.4 mm
dT = 20 C  ->  10.7 mm     <-- the width actually placed
dT = 30 C  ->   8.4 mm
dT = 45 C  ->   6.6 mm
```

The placed pours are exactly the ΔT = 20 °C width. Whoever sized them did it properly, and
**the copper-loss argument therefore does not justify four layers** — 3.1 W saved on a ~54 W
board, against pours that are already right.

---

## 21.3 The argument that actually decided it

**Four layers, 1 oz inner.** Four reasons, in order of weight.

**1. Choosing four now is free; choosing two and being wrong is not.** The placement is
identical either way — nothing already done is wasted. But if a 2-layer route ends with the
bottom pour shredded under the FET row, the remedy is not a tweak, it is a reroute. That
asymmetry settles the question on its own.

**2. The stackup geometry is doing work.** A standard 1.6 mm 4-layer puts thin prepreg
(~0.2 mm) between L1 and L2, with the thick core between L2 and L3. That places the ground
plane **0.2 mm** below the FET row instead of 1.44 mm away on the far side of a 2-layer board.
Loop inductance scales with that separation. This is the largest single benefit and it arrives
as a side effect of the stackup the fab builds by default.

**3. The current sense.** The protection scheme rests on a 0.5 mΩ shunt at 25 mV/A, amplified
×50, compared against thresholds sitting 224 mV below the top of the INA240's output swing. That
measurement must stay clean while 30 A commutates at ~0.5 V/ns centimetres away, and the
±45 A trip is the only thing between a fault and four destroyed FETs. A continuous plane under
that differential pair is cheap insurance on the circuit whose failure costs the most.

**4. The board composition is an unusually good fit.** 158 SMD footprints and 424 SMD pads
against **26 through-hole parts totalling 72 holes**. An inner plane here is nearly solid — close
to the full theoretical benefit, rather than a plane perforated into uselessness.

### The case against, recorded honestly

Two layers might well work, and the same SMD density that makes the inner plane good also means
less routing is forced to the bottom layer. The loss argument is genuinely weak. On a
cost-driven production run at volume, the 2-layer attempt should be made before spending the
money.

It is not that. It is a prototype whose foundational input — the coil — is still unmeasured, on
a design where the numbers have already moved three times. Margin gets bought where it is cheap.

**Rejected: 4-layer with 2 oz inner.** Halves coil loss to 4.65 W, but 2 oz inner layers are a
specialty order with a real cost step, to buy 4.6 W on a 54 W board. Revisit only if the thermal
budget turns out tight after the coil is measured.

---

## 21.4 Layer roles

| Layer | Copper | Role |
|---|---|---|
| **F.Cu** | 2 oz | Components, high-current pours, gate-drive loops |
| **In1.Cu** | 1 oz | **Solid GND plane. No routing, ever.** Unbroken under the FET row and the sense pairs — this is the thing being bought |
| **In2.Cu** | 1 oz | Paralleled high-current copper stitched to F.Cu, plus +60 V distribution |
| **B.Cu** | 2 oz | **The four 30 A coil pours**, plus logic and signal routing and GND fill stitched to In1.Cu. Amended 2026-08-24: see the note below |

> **Amended 2026-08-24, and this is a real change.** The coil pours were assigned to F.Cu. They
> cannot go there. Mapping every clear vertical channel on F.Cu, courtyards only, gives 5.80 mm
> in the band below the bridge, 8.30 mm through the logic blocks, 2.43 mm below them, and **no
> continuous channel of any width** from the bridge to the coil connectors. A 10.7 mm pour has
> nowhere to run. Necking one to the widest available 5.1 mm puts a 68 °C rise at 30 A right
> next to the current-sense amplifier.
>
> B.Cu is obstructed only by through-hole pads, 72 of them, and offers the full 159 mm width in
> both bands above the bulk row. The coil pours belong there, dropping through vias just after
> each shunt and landing at the connector, paralleled onto F.Cu wherever a channel exists. At
> 15 A per layer a 5.1 mm F.Cu run is only a 14.1 °C rise.
>
> In1.Cu then sits between the B.Cu coil currents and the F.Cu circuitry, shielding the sense
> amplifiers and comparators from 30 A passing underneath. That is a benefit of four layers
> nobody had articulated.
>
> Consequence: B.Cu logic gets routed **around** the pours, not the other way round. Signal
> demand is 3,126 mm of connection length, 5.6 % of one layer, against roughly 19 % for the
> pours, so there is room. The ordering has to be respected.

Target stackup, 1.60 mm total:

```
F.Mask    0.01
F.Cu      0.07     2 oz
prepreg   0.2      <-- keeps the GND plane close under the FET row
In1.Cu    0.035    1 oz
core      0.97
In2.Cu    0.035    1 oz
prepreg   0.2
B.Cu      0.07     2 oz
B.Mask    0.01
          1.60
```

**Confirm with the fab that 2 oz outer with 1 oz inner is available on 4 layers.** It is a
common combination, but some low-cost processes offer only 1 oz outer on 4-layer stackups, and
1 oz outer would **double** the pour losses to ~18.6 W. That would change the decision, not just
the quote.

---

## 21.5 Two constraints that fall out of the numbers

### The `HV_POWER` net class is a trap as configured

`HV_POWER` has a **3.0 mm track width** and its patterns cover `+60V`, `GND`, `*SW_*`,
`*COIL_*`, `*VB_*`, `*VBATT*`. A 3.0 mm track at 2 oz carrying 30 A gives, by IPC-2221, a
temperature rise of roughly **164 °C**. Three millimetres is 12 % of the required area.

**These nets must be routed as zones, never as tracks.** 10.7 mm of pour is the sized width.
The 3.0 mm class width is only safe for short stubs and for the genuinely low-current members
of the class — `*VB_*` is bootstrap, milliamps, and is in this class for its clearance, not its
width.

### Via stitching: the inner layer only helps if current can reach it

```
per-via current (25 um plating, IPC-2221 internal curve)
   0.3 mm drill    0.90 A @ dT=10 C     1.22 A @ dT=20 C
   0.4 mm drill    1.11 A @ dT=10 C     1.50 A @ dT=20 C
   0.6 mm drill    1.48 A @ dT=10 C     2.01 A @ dT=20 C

vias required to carry 30 A between layers
   0.3 mm drill    34 (dT=10)    25 (dT=20)
   0.4 mm drill    28 (dT=10)    21 (dT=20)
   0.6 mm drill    21 (dT=10)    15 (dT=20)
```

The `HV_POWER` via is already 1.2 mm / 0.6 mm drill, which is the right size.
**Budget 20 vias per 30 A layer transition** — dT = 10 °C with margin.

Sanity check: one 0.3 mm via, 1 mm long at 85 °C, is 0.919 mΩ; forty in parallel are 0.023 mΩ,
negligible against the 2.25–2.77 mΩ pours. Vias are a thermal limit here, not a resistive one.

---

## 21.6 Not yet done

Board Setup has **not** been reconfigured. Remaining:

1. Board Setup → Physical Stackup → **Copper Layers: 4**, then enter the §21.4 thicknesses.
   (F.Cu and B.Cu are already 0.07 from the §21.1 fix; the inner layers and dielectrics are new.)
2. Board Setup → Board Editor Layers → set **In1.Cu** and **In2.Cu** type to **power**.
3. Net classes: address the `HV_POWER` width trap per §21.5.
4. Confirm 2 oz outer / 1 oz inner with the fab.

---

## 21.7 Routing order

Deliberate: the loops that determine whether the board works get the copper first; the signals
that merely need to arrive get routed around them.

1. **Commutation loops** — bridge ceramics to FET drains and sources. Shortest, fattest, on
   F.Cu. Everything else routes around these.
2. **Gate loops** — gate and return as a tight pair per FET, over In1.Cu. These decide whether
   the FETs switch cleanly. The **low side** returns through the ground plane and closes its own
   loop. The **high side** returns through VS, a routed net on a node slewing at 0.5 V/ns, so HO
   and VS must be drawn as a deliberate pair or the loop area becomes whatever the router chose.
3. **Sense pairs** — Kelvin connections from the shunts to the INA240s, over unbroken plane,
   no crossings.
4. **High-current pours** — **coil pours on B.Cu**, paralleled onto F.Cu where a channel
   exists, 20 vias per transition. The +60 V bus zone on F.Cu paralleled onto In2.Cu.
   See the amendment in §21.4: F.Cu has no continuous channel wide enough for a coil pour.
5. **Bulk to bridge** — the ~81 mm feed.
6. **Logic and signals** on B.Cu, routed around the coil pours. `SD` is the fault shutdown
   line, sits at 767 Ω, and runs 45 mm past the bridge: keep it over the plane and away from any
   switching node.
7. **GND fill and stitching**, then DRC.

---

## 21.8 The coil pours as built

Drawn 2026-08-27. All four are on B.Cu, one polygon each, plus a small F.Cu landing zone
on each A leg. Measured with `tools/pour_check.py`, which rasterises the real outline at
0.05 mm rather than trusting its bounding box.

| Net | Narrowest cut in the conductor | dT at 30 A | Closest foreign copper |
|---|---|---|---|
| `/COIL_A1` | 11.00 mm | 19 C | 0.800 mm to H1 |
| `/COIL_A2` | 11.00 mm | 19 C | 0.800 mm to H2 |
| `/COIL_B1` | 10.70 mm | 20 C | 0.331 mm to Q4.3 [GND] |
| `/COIL_B2` | 10.70 mm | 20 C | 0.337 mm to Q203.2 [+60V] |

IPC-2221 external, 2 oz, `I = 0.048 * dT^0.44 * A^0.725`, A in mil^2. The 10.7 mm the
project sizes to is 20.3 C, not 20.0, which matters only because a checker comparing against
a computed 20 C flags the very width it is supposed to bless.

### The two legs are not built the same way, and the reason is the shunt

The A legs terminate on R11 and R219, which are surface mount. A pour on B.Cu cannot touch a
front pad, so each A leg needs a front landing zone off the shunt and a via field down to the
back: **15 vias at 2.0 A each on CH1, 19 at 1.58 A on CH2**, HV_POWER size, 1.2 mm pad on a
0.6 mm drill.

The B legs terminate on Q3/Q4 and Q203/Q204 and on the yoke connectors, all through-hole, so
the pour reaches every one of them down its own barrel. **No vias at all.**

That asymmetry is worth stating plainly because it looks like an inconsistency and is not: it
is the difference between a surface-mount current-sense resistor and a TO-220 lead.

### The fence at each TO-220 row

Pins sit on 2.54 mm pitch, and on both B legs each coil pin has a foreign neighbour 0.64 mm
away -- a gate on one side, a rail pin on the other. A single rectangle over the row would
enclose the gate pin and both rail pins, stranding each as a 0.3 mm island inside a node that
swings the full bus every cycle.

Both B pours instead stop below the row and send two narrow lobes up to the coil pins only.
No foreign pad ends up inside any coil pour on this board. The copper arriving at each pin is
then about 1.9 mm wide, which is the pad. **A TO-220 lead is the constriction and no pour
geometry can widen it** -- 4.7 to 5.0 mm total across both lobes, and `pour_check` now
recognises a cut that lands on the net's own pads and says so rather than calling it a neck.

### CH2's A leg is fenced too, and that one is a placement consequence

R11 sits at 180 degrees and R219 at 0, so the two shunts are 180-degree rotations of each
other rather than mirror images. Each block is internally consistent, tap and filter and
amplifier pin all on the same side, so nothing looks wrong until you try to take 30 A off the
pad:

```
R11.4  /COIL_A1  x[105.35,108.65] y[64.85,66.88]   open space directly above
R219.4 /COIL_A2  x[251.33,254.63] y[66.12,68.15]   SNS_N sits 0.51 mm above it
```

CH1's coil pad faces an empty band. CH2's is fenced by its own Kelvin tap, so its F.Cu zone
has to notch around SNS_N, and the current crosses that fence through two channels totalling
6.45 mm over a 1.36 mm length. Short constrictions between large copper areas are governed by
spreading rather than by the steady-state IPC curve, so the real rise is well under what
6.45 mm of continuous trace would give, but it is the one place where CH2 is worse than CH1.

The clean fix is rotating R219 to match R11, which drags R210, R211 and U203 with it to keep
the sense pair uncrossed. That is a block rework for a 1.4 mm constriction, so it is recorded
rather than done.

### What measurement caught that drawing did not

The pours were first built as overlapping rectangles, then redrawn by hand as single
polygons. The redraw was right everywhere that was hard -- both lobe pairs survived, no
foreign pad was enclosed, all 34 vias stayed inside their zones on both layers, and
`COIL_A1_F` came out better than the rectangle it replaced because its staircase swallows
R11 pad 4 whole instead of clipping its edge.

What it got wrong was one horizontal edge on each B leg landing at y=134 instead of 138.2.
That made both bands **6.50 mm where they needed 10.7**, held for 33 mm on CH1 and 27 mm on
CH2, for a 46 C rise. Invisible on canvas. Obvious the moment something measured it.

`lay.py` could not have caught it: its zone check treats a zone as its bounding box, which is
exact only while zones are rectangles. `pour_check.py` exists because that assumption died
the moment the pours became polygons.

### Still open on these nets

`U2.6`, `C16.2`, `R6.1` and `U207.6`, `C226.2`, `R224.1` -- the high-side drivers' VS
references, their bootstrap capacitors and a gate resistor each. All surface mount, none
carrying coil current. They are a routing job, and DRC will keep listing the coil nets as
unconnected until it is done.

---

## 21.9 Planes are not traces, and A17 was computing the wrong one

A17 said the bulk-to-bridge feed needs 28.0 mm and concluded the 13 mm corridor could not carry
it. That number came from the IPC-2221 trace formula. The feed is not a trace.

Push the same formula onto In2.Cu at 1 oz and it asks for **146 mm** of width for 60 A at
dT = 20 C. The board is 160 mm wide. When a formula demands the entire board, the honest
reading is that it is being asked a question it was not calibrated for: it models a narrow
conductor losing heat to the laminate around it, and a plane is its own heat spreader.

### Count squares instead

```
1 oz copper   0.494 mOhm / square          2 oz copper   0.247 mOhm / square

cap row y=143 to bridge row y=62     81 mm long, about 150 mm wide
                                     0.54 squares  ->  0.267 mOhm
                                     16 mV and 0.96 W at 60 A

spreading at one bulk cap pad        a = 1.2 mm, b = 8.5 mm   0.154 mOhm
  six of them in parallel                                     0.026 mOhm
spreading at one FET drain pin       a = 0.98 mm, b = 8 mm    0.165 mOhm
                                     5 mV and 0.15 W at its own 30 A

end to end                           about 0.46 mOhm
                                     27 mV and 1.65 W at 60 A
                                     0.14 mW/mm2 over 150 x 80 mm
```

Two orders of magnitude below what a board dissipates comfortably. The corridor width was never
the constraint. What matters for a plane is that it stays a plane.

### Which is why In2.Cu still carries no signals

The original reason stands and is now the only reason: a route across In2.Cu cuts the plane, and
a cut plane forces the current around it. That is how a plane turns back into a trace, and the
trace numbers really are as bad as A17 first suggested.

### The power path needs no vias

Every +60 V pad that carries current is through-hole:

```
Q1.2  Q3.2  Q203.2  Q201.2       FET drains, y = 62
C101.1 ... C106.1                bulk caps,  y = 143
J101.1                           bus input,  (153.5, 182.5)
```

So an In2.Cu plane reaches all eleven down their own barrels. Vias are needed only to bring the
surface-mount bridge ceramics on F.Cu onto the plane, and those carry ripple, not bus current.

### The In2.Cu split, and why the bottom of the board is not +60 V

The stackup is F.Cu / In1 GND / In2 +60V / B.Cu, so B.Cu's nearest plane is In2. Over the power
section that is fine: the bus is an AC ground, bypassed by six bulk caps and by the interplane
capacitance of In1 against In2 (about 0.9 nF across the 0.97 mm core).

Under the IO connectors it is not fine. J202 carries the PWM inputs, the enable lines and the
two current-sense outputs off the board, and those are the signals whose reference quality
matters most. So In2 is split: **+60 V above y = 150 plus a finger down to J101, GND below it.**
The finger runs x 146 to 162, which clears J202's leftmost pin at x = 169 by 7 mm.

A split plane is a hazard wherever a signal crosses the split. Nothing crosses it yet. Anything
routed on B.Cu across y = 150 between x = 143 and x = 165 later will need a return path checked
by hand.

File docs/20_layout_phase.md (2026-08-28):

# 20 — PCB layout phase: placement, review, and the CH2 leg swap

**Status:** placement complete and verified. Routing not started.
**Board:** 160 × 140 mm, outline (100,50)–(260,190), 184 footprints.
**DRC:** clean except unconnected items (expected — nothing is routed).

---

## 20.1 Why the board grew from 160 × 100 to 160 × 140

The bulk capacitor bank did not fit.

C101–C106 are Rubycon ZLH 470 µF / 100 V in Ø16 × 31.5 mm cans
(`100ZLH470MEFC16X31.5`), six of them, and the plan was to sit them between the two coil
connectors. They did not fit, and I did not catch it because **I was checking pad extents
instead of courtyards.**

That is worth recording as a method error, not just an outcome. The Molex 38969-0002 coil
connector has a courtyard of 26.6 × 29.9 mm — far larger than the region its pads occupy. On
pad extents alone, J203 and J204 read as "clear" with room between them. On courtyards they
do not. I declared the placement feasible on the wrong measurement, and Sebastian caught it
from the canvas before I did.

The clearance checker was rewritten to read `F.CrtYd` geometry — `fp_line`, `fp_poly`,
`fp_rect` **and** `fp_circle` (centre + end → radius, which is how KiCad stores the courtyard
of a radial electrolytic). Every clearance number in this document comes from that path.

Board grew to 140 mm tall. The bulk row now sits below the connectors at y = 150 on roughly
17 mm pitch, x = 134…218.

---

## 20.2 Floorplan

```
y  50– 59   heatsink shadow (extrusion covers x 122..243, face at y ~= 58.6)
y  59– 71   FET row (y=62) + bridge ceramics (y=66) + 100nF (y=69.5)
y  71– 93   gate networks, drivers (y=77), bootstrap (y=88), sense clusters
y  96–135   CH1 logic (x 108–160), CH2 logic (x 173–225, = CH1 + 65)
y 141–158   bulk cap row, y=150, ~17 mm pitch, x 134..218
y 158–190   J101, J202, J201, IO passives
edges       J203 (107.5, 157.5 rot 90), J204 (252.775, 145.166 rot -90)
```

### The FET ordering is thermal, not electrical

Under unipolar 3-level PWM at the D = 0.75 design point, conduction splits 3:1. Q1 (leg A
high side) and Q4 (leg B low side) conduct 75 % of the period **and** take all of the hard
switching. Q2 and Q3 conduct 25 % and switch at zero volts.

So two devices per channel run hot and two run cool, and they are placed to alternate:

```
CH1   Q2 (cold)  Q1 (hot)  Q3 (cold)  Q4 (hot)      x = 125, 140, 155, 170
CH2   Q202(cold) Q201(hot) Q203(cold) Q204(hot)     x = 190, 205, 220, 235
```

C-H-C-H, so no two hot devices share a heatsink segment. This ordering is a constraint on any
future re-placement, not an accident of layout.

---

## 20.3 Verified placement metrics

All measured from `final_lev.kicad_pcb` geometry, not from screenshots.

| Metric | Value |
|---|---|
| Courtyard overlaps | **0** across all 184 footprints |
| Commutation loop, CH1 leg A | 17.7 / 17.8 mm (two nearest ceramics) |
| Commutation loop, CH1 leg B | 16.7 / 16.8 mm |
| Commutation loop, CH2 leg A | 17.7 / 17.8 mm |
| Commutation loop, CH2 leg B | 16.7 / 16.8 mm |
| Gate turn-off loop | 19.6 – 27.4 mm, identical on both channels |
| Bootstrap cap → VB/VS | 3.3 – 6.4 mm |
| Sense pair routing | no crossing; 2.5 mm P/N length mismatch |
| Closest HV ↔ LV approach | 2.88 mm |
| Heatsink shadow intrusions | none |
| Mounting hole keepouts | 12 – 28 mm |
| Closest footprint → outline | J204 at 0.175 mm |

**Loop metric, stated explicitly**, because figures under a different definition were quoted
earlier in this project and the two are not comparable: the number is a **two-segment path
length** — high-side drain pad to the ceramic's +60 V pad, plus the ceramic's GND pad to the
low-side source pad. It is not a closed-loop perimeter and it does not include the ceramic's
own internal path or via inductance. All four figures are produced by `tools/lay.py`.

### Known cost, accepted for now

Copper loss on the coil and bus runs at 30 A on a 10.7 mm pour:

```
CH1  shunt -> J203        91.7 mm    ~1.9 W
CH1  SW_B  -> J203        92.0 mm    ~1.9 W
CH2  shunt -> J204        78.0 mm    ~1.6 W
CH2  SW_B  -> J204        95.9 mm    ~2.0 W
     bulk cap -> bridge drain  ~81 mm
                          total     ~8.7 W
```

Reducing this means restructuring the floorplan — roughly 50 further part moves — and it
trades against the connector positions, which are set by the mechanical interface. Recorded
as a known cost rather than an oversight. Revisit if the thermal budget tightens after the
coil is measured.

---

## 20.4 The one structural defect found: CH2's SW_A run

CH2 was built as an exact +65 mm copy of CH1's FET row. That is the right instinct for two
identical channels and it is wrong here, because **the coil connectors are mirrored** — J203
sits to the *left* of CH1, J204 sits to the *right* of CH2.

Consequence: CH1's leg A is adjacent to its shunt (R11) and connector. CH2's leg A is as far
from J204 as the board allows. Its SW_A node — 0 to 60 V, slewing at roughly 0.5 V/ns — has
to cross leg B's high-current territory to reach the shunt at x ≈ 248.

**The fix is to swap leg A and leg B within CH2**, making CH2 a true mirror of CH1 rather than
a translation of it. Leg B moves −30 mm in X, leg A moves +30 mm in X. Y and rotation are
unchanged on every part, because each leg keeps its internal low/high ordering.

### Verified before recommending

| | before | after |
|---|---|---|
| CH2 SW_A net span | 55.6 mm | **25.8 mm** |
| CH2 Q201 pad 3 → R219 pad 1 | ~38 mm | **7.94 mm** |
| CH2 COIL_B2 net span | 97.0 mm | 105.8 mm |
| sum of the two | 152.6 mm | **131.6 mm** |
| courtyard overlaps | 0 | **0** |
| CH2 leg A commutation loop | 17.7 mm | **17.7 mm** |
| CH2 leg B commutation loop | 16.7 mm | **16.7 mm** |
| thermal order | C-H-C-H | **C-H-C-H** |
| heatsink shadow intrusions | none | none |
| closest moved part → M3 hole | — | 12.73 mm (Q201 → H2) |
| closest moved part → outline | — | 8.60 mm |

COIL_B2 gets 8.8 mm longer. That is the honest cost. It buys a 30 mm reduction on SW_A and,
more importantly, removes the crossing: after the swap COIL_B2 runs down open board to the
connector, which is structurally identical to what CH1 already does (COIL_B1 spans 97.8 mm).
The commutation loops do not change at all.

**Correction.** When this was first reported in chat I said the two legs "trade" loop values,
17.7 ↔ 16.7. That was a misreading of my own output. The loops are **unchanged**, and they
have to be: the ceramics move with their blocks and land on each other's coordinates, so each
leg finds a ceramic at exactly the same distance as before. Same reason the board comes out
identical whether the ceramics are included in the selection or not. The corrected figures are
in the table above and are reproducible with `tools/lay.py`.

### Two findings that made the edit safe

**1. Every leg-local net is fully contained in its block.** Audited from the netlist:

```
/CH2/G_Q1  G_Q2  HO_A  LO_A  VB_A   -> 100% inside leg A
/CH2/G_Q3  G_Q4  HO_B  LO_B  VB_B   -> 100% inside leg B
/CH2/SD                             -> spans both (logic net, both drivers)
/CH2/SW_A                           -> touches R219, the shunt, which does not move
```

So the gate loops and bootstrap loops translate rigidly and do not change at all. If any
gate resistor or bootstrap part had been left outside its block, the move would have silently
stretched a gate loop.

**2. The bridge ceramics inside each block are spaced exactly 30 mm apart.**

```
C212 192.5   C214 198.5   C215 204.5   C216 210.5   C217 201.5
C219 222.5   C220 228.5   C221 234.5   C222 240.5   C223 231.5
```

Every pair differs by exactly +30.0 mm. They are +60 V → GND bus decouplers, common to both
legs, so they are not associated with a leg electrically — and because they are spaced at the
shift distance, moving them with their block lands them precisely on each other's old
coordinates. The resulting board is identical either way, which means they can be included in
a blind window-select instead of being carefully excluded. That turns a 32-part hand-pick into
two rubber-band drags.

---

## 20.5 J203 outline violation — resolved

J203's courtyard left edge sat at x = 99.950 against a board edge of x = 100.000: 0.050 mm
**outside** the outline. Resolved by moving J203 from x = 107.0 to x = 107.5 (y snapped to
157.5, rotation 90 unchanged). Left margin is now 0.450 mm. J204's right margin is 0.175 mm.
Both inside, zero courtyard overlaps board-wide.

---

## 20.6 Process notes carried forward

- **No file surgery while KiCad is open.** A reference designator was renamed externally
  while the editor held the file; the next save from KiCad overwrote it. All external patching
  is now batched to periods when the editor is closed.
- **Check courtyards, never pad extents.** See 20.1.
- **KiCad multi-instance hierarchy**: per-instance reference designators live in
  `(instances (project ... (path "<uuid>" (reference "X") (unit N))))`. Both the reference
  *and* the unit field must be patched, and a uniqueness check must key on `(ref, unit)` —
  multi-unit parts legitimately repeat their reference across units.
- **KiCad transform**: `a = radians(-ang); out = (x + lx·cos a − ly·sin a, y + lx·sin a + ly·cos a)`.
- **Pad net syntax in this file** is `(net "NAME")` with no net number.

---

## 20.8 Leg-A bridge ceramic orientation

> **Superseded 2026-08-27 by 20.11.** The conclusion reached in this section, that the
> `lib_footprint_mismatch` warnings were unexplained and safe to ignore, was wrong. The
> warning was correct and the cause is isolated in 20.11. Everything else in this section
> stands. It is left in place because the reasoning that produced the wrong call is the
> point of keeping it.

Found 2026-08-24 while laying out the CH1 leg A commutation loop, before any copper was
placed.

The C-H-C-H thermal ordering in §20.2 forces the two legs into opposite pin orders:

```
leg A:  Q2 (low)  then Q1 (high)   ->  GND  at x = 130.08,  +60V at x = 142.54
leg B:  Q3 (high) then Q4 (low)    ->  +60V at x = 157.54,  GND  at x = 175.08
```

Leg A therefore wants +60 V on its **right**; leg B wants it on its **left**. Every bridge
ceramic was placed at 0°, which puts pad 1 (+60V) on the left — correct for leg B, backwards
for leg A. Nobody chose this: it is the library default orientation meeting a constraint that
came from thermals.

| | before | after |
|---|---|---|
| CH1 A loop | 17.72 / 17.79 mm | **12.89 / 13.08 mm** |
| CH2 A loop | 17.72 / 17.79 mm | **12.89 / 13.08 mm** |
| CH1 B loop | 16.73 / 16.81 mm | 16.73 / 16.81 mm |
| CH2 B loop | 16.73 / 16.81 mm | 16.73 / 16.81 mm |
| board worst-case loop | 17.79 mm | **16.81 mm** |
| courtyard overlaps | 0 | **0** |
| heatsink-shadow intrusions | none | none |

**27 % off leg A for a rotation.** Ten parts — C3, C5, C6, C7, C8 and C212, C214, C215, C216,
C217 — 0° → 180°. X, Y, nets and courtyards unchanged; pad 1 keeps net `+60V` and simply lands
on the other side of the body. Leg B’s ceramics (C11–C15, C219–C223) stay at 0°, where
rotating them would make things worse: 16.73 → 22.26 mm.

Applied by `tools/rot_ceramics.py --write` with KiCad closed. 80 lines changed of 59,584.

### The file format was established, not assumed

A 0 → 180 rotation was not guessed at. It was derived by diffing U1 (0°) against U2 (180°) —
the same SOIC-8 footprint, in this same board file:

```
U1   (at 132.5 77)       Reference (0 -3.5 0)    fp_text ${REFERENCE} (0 0 90)
U2   (at 162.5 77 180)   Reference (0 -3.5 180)  fp_text ${REFERENCE} (0 0 270)
```

So KiCad adds the angle to the footprint’s own `(at)` and adds 180 to the angle field of every
`(at)` inside a `property` or `fp_text` sub-block, leaving local offsets, pads and graphics
alone — 8 `(at)` lines per capacitor here. Patching only the footprint angle would have left
these ten silkscreen designators stored differently from every other rotated part on the board.

### The check lives in the tool

`rot_ceramics.py` refuses to run while `~final_lev.kicad_pcb.lck` exists, so the "no file
surgery while KiCad is open" rule is enforced rather than remembered. It reads and writes
bytes, so CRLF survives. After patching it re-parses **its own patched buffer**, recomputes all
four commutation loops and the full 184-footprint courtyard check from the patched geometry,
and writes nothing unless those agree. The numbers it prints are the ones it computed.

---

### The library-mismatch warning it produced, and what that turned out to be

After the rotation, DRC reported ten `lib_footprint_mismatch` warnings, and the flagged list was
exactly the ten rotated parts: C3, C5, C6, C7, C8, C212, C214, C215, C216, C217. None of the
untouched 1210s — C12–C15, C219–C222 — appeared.

That looked conclusive, and it was wrong. The rotation was redone in the KiCad GUI (Orientation
0 → save → Orientation 180 → save) and the ten warnings persisted. Diffing each footprint block
before and after that GUI round trip: **identical, to the byte.**

So the file patch and the editor converge on the same board. The warning is not an artefact of
external editing — it is what KiCad 10 reports for these capacitor footprints at 180°, and it
would have appeared identically had the rotation been done by hand from the start.

The geometry was verified against the actual library file from this machine
(`Capacitor_SMD/C_1210_3225Metric_Pad1.33x2.70mm_HandSolder.kicad_mod`, same `(version
20260206)` as the board). Compared as parsed S-expressions rather than as text, the only
differences are the board placement coordinates and the Reference text offset — and C13, which
differs from the library in *both* Reference offset values and is **not** flagged, rules that
out as the trigger. Pads, courtyard rect, F.Fab rect, both silk lines, `attr` and the 3D model
path are identical.

**Conclusion: cosmetic, cause not isolated, geometry confirmed identical.** Severity set to
Ignore, with this note as the reason. What must *not* be done is **Update Footprints from
Library** — it would replace the board footprints wholesale, and every clearance and loop figure
in this document is measured from that geometry.

### A correction, and then a correction to the correction

This section first claimed the tool "reproduces exactly what the KiCad GUI writes". That was
retracted when KiCad was seen rewriting the patched text-field offsets on save — `(at 0 2.5
180)` came back as `(at 0 -2.5 180)`. The retraction was itself too broad: KiCad normalises
those offsets on load, and after one save cycle the file is byte-identical to the GUI result.
Both statements stay on the record because both were made.

The durable lesson is narrower than "don’t patch files": **a claim about file format is worth
only what a round trip through the application proves.** The patch was correct. The check that
would have shown it was correct — reopen, save, diff — was not run at the time.

---

## 20.9 Block-by-block placement review

**2026-08-24.** Placement had been called complete and verified, and it was, on the six things
`lay.py` measured. A remark from outside the project ("the filter capacitors for the I/O should
be close to the pins") found a whole category the checker was blind to. Rather than re-place the
board, the eight functional blocks were walked one at a time: what each is for, what the file
measures, whether it meets the intent.

`lay.py` was extended first with eight new checks, so the review's findings are reproducible
rather than anecdotal. See the PLACEMENT CHECKS section of that script; its thresholds are named
constants with the reasoning above them.

### What each block came to

| Block | Verdict |
|---|---|
| 1 bridge | Meets intent. Loops 12.9 / 16.7 mm, FET bodies flush on the heatsink face, thermal order preserved |
| 2 gate drive | Meets intent. Loops 32.9 to 37.4 mm, channels matched within 0.4 mm, bootstrap 10.3 to 10.8 mm |
| 3 current sense | One finding: `C211` on the wrong side of `U203` |
| 4 protection | Six findings: every capacitor around both comparators |
| 5 logic and MCU | One finding: `R238` |
| 6 bus and bulk | No findings. Bulk bank within 1.9 mm of uniform. Two open questions |
| 7 coil paths | **Structural.** The coil pours cannot go on F.Cu |
| 8 mechanical | Sound. One stale register entry, A11 |

### The pattern worth naming

Four separate findings were the same underlying mistake: **a block mirrored for CH2 where one
part kept CH1's geometry.** The bridge ceramics facing the wrong way (§20.8), `C211` left above
a package that had been rotated 180°, `R238` translated with the block instead of mirrored with
it, and the CH2 leg order itself (§20.4). Anything added to this board should be checked against
that first.

### Moves applied

Eight parts, by `tools/place_caps.py`, from the decoupling failures:

```
C20  -> U3.6      58.17 mm -> 2.36      C213 -> U203.6   38.95 -> 2.34
C1   -> U1.5       6.26    -> 2.76      C2   -> U1.5      4.31 -> 2.19
C227 -> U206.5     6.26    -> 2.76      C228 -> U206.5    4.31 -> 2.19
C209 -> J202.15   19.89    -> 2.37      C210 -> J202.16  28.60 -> 2.43
```

Eight more by `tools/place_review.py`, from the block walk:

```
C211 -> U203.8     7.05 mm -> 3.41      R238 -> U207.1   46.87 -> 26.57
C25  -> U4.3       5.56    -> 2.39      C235 -> U204.3    5.56 -> 2.31
C26  -> U4.6      12.78    -> 2.39      C237 -> U204.6   12.78 -> 2.31
C27  -> U4.2      10.46    -> 2.62      C239 -> U204.2   10.46 -> 3.12
```

`lay.py` placement checks went **7 FAIL / 16 warn** to **1 FAIL / 10 warn**. The remaining
failure is the absence of test points; the remaining warnings are supply pins in the 3.8 to
5.3 mm band and the two `/RESET` time-constant capacitors, which the checker cannot distinguish
from noise filters and therefore reports rather than grades.

Courtyard overlaps stayed at 0 and the commutation loops stayed at 12.9 / 16.7 mm through both
batches.

### Things checked that turned out fine, recorded so nobody checks them twice

- The 81 to 93 mm PWM runs from buffer to driver need no series termination. Round-trip delay
  1.12 ns against a 2 ns edge; reflections settle inside the edge.
- The 3.3 V buffers drive the IR2184 inputs with 0.6 V of margin. VIH is 2.7 V minimum and the
  part is specified 3.3 V logic compatible.
- The 45 mm shutdown run at 767 Ω picks up about 38 mV from a 0.5 V/ns neighbour through a
  plausible 0.1 pF. Nowhere near a logic threshold.
- All six bulk electrolytics share one polarity orientation, which is a deliberate assembly
  safeguard.

### Open, and belonging to somebody else

The TVS clamps sit 70 mm from the bus connector and 53 mm from the bridge, and the bridge has no
room for them: respecting the heatsink shadow and every courtyard, the closest either can get is
27.5 and 37.2 mm. What they are for should be settled before spending a rearrangement on them.
Separately, this board has no surge protection where the harness lands.

Bleed timing, for anyone about to probe it: 62 second time constant, below 50 V in 11 seconds,
below 5 V in two and a half minutes, 5.1 J stored at 60 V.

---

## 20.10 Test points

Thirteen test points were added to the schematic and placed on 2026-08-27. Before this the
board had nowhere to put a probe, and adding probe points after routing means ripping up
copper to make room for them.

| Ref | Net | Why it is there |
|---|---|---|
| TP201 / TP202 | `/ISNS1`, `/ISNS2` | The amplifier output. This is the one signal that has to be believed, because the overcurrent trip is derived from it. |
| TP203 / TP204 | `/CH1/SD`, `/CH2/SD` | Shutdown. Tells you whether the driver was commanded off or fell over on its own. |
| TP205 / TP206 | `/CH1/FAULT_N`, `/CH2/FAULT_N` | The latch output. Says a fault was captured even after the event has passed. |
| TP207 / TP208 | GND | Ground reference for the six signals above, one per channel. |
| TP209 / TP210 / TP211 | +12V, +5V, +3.3V | Rail check at the regulators, not at a load. |
| TP212 | GND | Ground reference for the three rails. |
| TP213 | GND | Bridge-side ground, in the clear channel between the two channels. |

### Ground first, then signals

The placement rule was that a signal measurement is only as good as its ground reference, so
the three ground points were placed first, against the part each group serves, and the signal
points were clustered around **their own ground** rather than against the net they measure.
A 6 mm trace out to a test point costs nothing on these signals. A 60 mm probe ground lead
turns a clean edge into ringing that is not on the board.

Worst signal-to-ground distance came out at 7.50 mm (TP205), against a limit of 8.0 mm written
into the tool. Every other pair is under 6.5 mm.

### What the first solve got wrong

TP213 landed at (134.6, 62.0), in the 4.5 mm gap between Q2 and Q1 — geometrically legal,
under the heatsink extrusion, and impossible to reach with a probe hook. The same solve also
scattered each channel's ground as far as 45 mm from the signals it was supposed to reference,
which defeats the entire point of having it. Both came from optimising distance-to-net instead
of distance-to-ground, and from a keepout list that had the heatsink shadow but not the
question "can a hand get here."

Re-solved with grounds placed first. TP213 now sits at (183.25, 70.0), in the open channel
between the channels.

### Keepouts the search respected

Courtyards and the board edge, the heatsink shadow, and the four 10.7 mm coil-pour corridors
on B.Cu. That last one matters because these are through-hole wire loops: a barrel dropped in
a corridor punches a hole through a pour that has to carry 30 A.

### One silkscreen collision, fixed by moving the label

TP204 and TP208 sit 3.72 mm apart and both inherited the library's default reference position
at (0.7, 2.5), which put their labels 3.60 mm apart in x against a 3.75 mm text width. TP204's
label moved to (-2.6, 0), to the left of the loop. Nothing electrical moved. `check_silk` now
reports zero overlapping pairs.

### State after

`tools/place_testpoints.py`, dry run then `--write`, backup to `final_lev.kicad_pcb.bak1`.

```
test points patched  : 13
silk labels moved    : 1  TP204
line endings         : CRLF 62554 -> 62554   bare LF 0 -> 0
courtyard overlaps   : 0
```

`tools/lay.py`: **0 FAIL, 10 warn**, down from 1 FAIL / 10 warn. Commutation loops unchanged
at 12.9 / 13.1 / 16.7 / 16.8 mm, heatsink shadow still clear, 197 footprints.

### A12 corrected as a consequence

Pushing the test points to the board produced `No net found ... no pin 1 in symbol` on H1-H4.
My first answer, that the holes are plain unplated-net holes with no pad and no net, was
**wrong**, and is corrected here. They are `MountingHole_3.2mm_M3_Pad`: a plated 3.2 mm hole
with a 6.4 mm pad on all four copper layers, carrying no net. The warning comes from the
symbol, which has no pin for the pad to take a net from. The A12 row had separately claimed a
0 Ω 1206 chassis-bond jumper fitted DNF; that part does not exist in the netlist and never
did. A12 now records both facts and the real fix, which is a symbol swap rather than a re-spin.

The wrong answer came from a parser of mine that searched for `(net <number> "NAME")`. This
file writes `(net "NAME")` with no number, on all 506 pads. The regex matched nothing, returned
an empty list, and I read empty as *absent* instead of *unmatched*. Same failure mode as 20.8
and as the first version of `check_pad_orientation`: my own tool's silence was taken as
evidence. Every parser here should assert that it matched something before anyone believes
what it did not find.

---

## 20.11 The footprint-mismatch warning was real, and 20.8 was wrong about it

`§20.8` looked at KiCad's `lib_footprint_mismatch` warnings, checked the geometry against the
library, found it identical, failed to isolate a cause and set the severity to Ignore. That was
the wrong call, and this section replaces it. The warning was accurate. Something in those
footprints genuinely did not match the library, and it was not cosmetic.

### What the DRC report actually contained

Run 2026-08-27 13:47 on KiCad 10.0.5, two separate things:

| Kind | Count | Meaning |
|---|---|---|
| `unconnected_items` | ~300 | The board has 0 tracks, 0 vias and 1 zone, so every connection is unrouted. This is the routing to-do list, not a fault. It also confirms the netlist pushed cleanly: every pad carries the net it should. |
| `lib_footprint_mismatch` | 18 | All capacitors. This one was real. |

### The defect

A pad's `(at x y angle)` in this file is the pad's **absolute** angle, so a body rotated to 90
normally has its pads written at 90. Twenty footprints did not follow their body:

```
C1  C20  C227  C213  C239        pads 90 deg off  -> the 1.175 x 1.450 mm pad turned across the part
C3  C5  C6  C7  C8  C210
C212 C214 C215 C216 C217
C235  C237                       pads 180 deg off -> same rectangle, cosmetic
```

Off by 180 a rectangle is unchanged. Off by 90 the pad's length and width swap and the copper
stops matching the part's terminations. Five parts were in that state, and they would have been
fabricated that way.

Cause: `rot_ceramics.py`, `place_caps.py` and `place_review.py` all rewrote a footprint's `(at)`
line and left its pads behind. Every footprint KiCad itself rotated on this board obeys the rule
(C19 at 180 with pads at 180, C25/C26/C27 and C203 at 90 with pads at 90, D1 at 180 with pads at
180), which is the in-file evidence for what the convention is.

### The fix

Pcbnew, **Tools -> Update Footprints from Library**, all footprints, field-reset boxes left
unchecked. KiCad rewrote each footprint body from the library at its existing position and
orientation. No footprint moved or rotated: 197 before, 197 after, all 197 at identical
coordinates. The only other change was 23 reference-designator label positions, which KiCad
re-placed itself, and that incidentally resolved the TP204 / TP208 silkscreen overlap that
`place_testpoints.py` had hand-fixed. `check_silk` still reports 0 overlapping pairs.

### The check, and the mistake inside the first version of it

`lay.py` gained `check_pad_orientation`. Its first version assumed a pad's angle should equal its
body's angle, which flagged D2 and D205, the two SMC TVS clamps, as broken. They are not.
`Diode_SMD:D_SMC_Handsoldering` declares its pads 90 degrees off its own outline in the library,
and D2 and D205 inherit that honestly. Running the library update proved it: KiCad rewrote both
from the library and left them exactly where they were.

The rule is therefore not "pad angle equals body angle" but **"pad angle minus body angle is the
same for every placement of the same library footprint."** The baseline is whatever that
footprint's other instances use. That is what the check now does, and it is what made the five
real failures visible in the first place: 5 parts sitting at 90 in a population of 41 that was
otherwise 0.

Regression tested both ways. Against the pre-update board it reports the 5 FAIL and 13 warn.
Against the current board it reports zero, and no longer accuses D2 or D205.

### Worth naming

The 20.8 error and the first-version-of-the-check error are the same error twice: **a check I
wrote said the geometry was fine, so a warning the application raised got suppressed.** KiCad was
right both times. A tool's warning outranks my tool's clean bill of health until my tool has been
shown to look at the same thing the application is looking at.

### State after

`tools/lay.py`: **0 FAIL, 10 warn.** 197 footprints, 0 courtyard overlaps, commutation loops
unchanged at 12.9 / 13.1 / 16.7 / 16.8 mm, heatsink shadow clear, 13 test points, 0 silkscreen
collisions.

---

## 20.7 Open after this phase

| Item | Note |
|---|---|
| ~~2 layers vs 4 layers~~ | **Settled 2026-08-24: four layers, 1 oz inner.** Reasoning in `21_stackup_and_layers.md`; Board Setup reconfigured. |
| ~~CH2 leg swap~~ | **Applied and verified 2026-08-24.** `/CH2/SW_A` 55.6 → 25.8 mm. |
| Coil L, R, k | Still unmeasured. Everything thermal depends on it. |
| §4.1 thermal numbers | Still derived under locked antiphase; must be redone under unipolar. |
| Bus-fault detector §3.2 | Undesigned. |
| ~8.7 W coil/bus copper loss | Known cost, see 20.3. |

The layout is in the same position the schematic was: structurally sound, and resting on a
coil measurement nobody has taken yet.

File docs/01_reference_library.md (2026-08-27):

# Reference Library — Levitation Coil Drive Stage

Every link below was opened and verified against its claimed content. Aggregator sites
(alldatasheet, datasheet4u, scribd, academia.edu) were rejected — first-party
manufacturer domains only. Items that could not be verified are listed as **not found**
rather than substituted with a guess.

Last verified: 2026-08-11

---

## 1. Gate drive

| Document | What it solves | Read |
|---|---|---|
| **IR2184 datasheet** (PD60174 Rev. G, Infineon/IR) ⚠️ *the link resolves to a file named `infineon-ir21844s-datasheet-en.pdf`; the IR21844 is a different part with an adjustable deadtime pin, so confirm this is the IR2184 before relying on it* · [PDF](https://www.infineon.com/assets/row/public/documents/24/49/infineon-ir21844s-datasheet-en.pdf) | The driver in the current BOM. 600 V floating channel, 1.4 A source / 1.8 A sink, programmable deadtime 280–520 ns. | The **V_BS UVLO 8.0–9.8 V rising** spec — this is what sets your bootstrap refresh requirement. And the **R_DT deadtime table**. |
| **AN-1123** *Bootstrap Network Analysis* (Infineon) · [PDF](https://www.infineon.com/assets/row/public/documents/24/42/infineon-bootstrap-network-analysis-applicationnotes-en.pdf) | **The single most important document for this design.** Quantifies why a bootstrap supply fails at high duty cycle. | **§2.2 pp. 5–6**: ΔV_BS = Q_TOT/C_boot, and Eq. 7 giving the duty-cycle boundary D < 4·R_boot·C_boot/T_S. **§3 pp. 11–13**: worked sizing examples. |
| **AN_2203** *Gate drive for power MOSFETs in switching applications* (Infineon, V1.0 2022) · [PDF](https://www.infineon.com/assets/row/public/documents/24/42/infineon-gate-drive-for-power-mosfets-in-switchtin-applications-applicationnotes-en.pdf) | Gate resistor selection and the alternatives to bootstrap. | **§4** gate drive voltage/current and R_G selection. **§6.1–6.7** floating/high-side drive: pulse transformers, half-bridge driver ICs, isolated drivers. |
| **SLVA444** *Providing Continuous Gate Drive Using a Charge Pump* (TI, Feb 2011) · [PDF](https://www.ti.com/lit/an/slva444/slva444.pdf) | The concrete fix if you must run 100 % duty. | **§3 pp. 4–6**, Figure 4 (NE555 charge pump) and Figure 6. |

> **Not found:** IR Design Tip **DT04-4**. Only aggregator copies exist; Infineon does not
> host the legacy IR design tips. AN-1123 + AN_2203 cover the same material.

---

## 2. MOSFET selection, loss and thermal

| Document | What it solves | Read |
|---|---|---|
| **IRF100B201 datasheet** (Infineon/IR, 2015) · [PDF](https://www.infineon.com/assets/row/public/documents/24/49/infineon-irf100b201-datasheet-en.pdf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) | The FET in the current BOM. 100 V, R_DS(on) 3.5 mΩ typ / 4.2 mΩ max, **Q_g 170 nC typ**, R_thJC 0.34 °C/W, TO-220AB. | **Fig. 10 p. 5** safe operating area. **Fig. 14 p. 6** transient thermal impedance — this is the curve you need for pulsed peak current. |
| **AND9083/D** *MOSFET Gate-Charge Origin and its Applications* (onsemi, Rev. 2) · [PDF](https://www.onsemi.com/pub/Collateral/AND9083-D.PDF) | Closed-form loss equations. | **Eq. 7** — switching loss for **inductive (hard-switched)** loads, which is your case: P_SW = ½·V_DD·I_D·(t_SW(ON)+t_SW(OFF))·f_SW. Eq. 4 gate-charge loss, Eq. 5–6 switching time from Q_SW, R_DR, R_G. |
| **AND8220/D** *How To Use Thermal Data Found in Data Sheets* (onsemi, Rev. 1 2022) · [PDF](https://www.onsemi.com/download/application-notes/pdf/and8220-d.pdf) | Why R_thJA numbers mislead, and how to build an honest junction-to-ambient budget. | **pp. 6–7** θ_JA vs. copper area curves per copper weight. **pp. 3–4** worked heatsink example. |
| **AN-949** *Current Rating of Power Semiconductors* (Vishay Siliconix, doc 91419) · [PDF](https://www.vishay.com/docs/91419/appnote9.pdf) | Sanity check against over-trusting datasheet current ratings. | Notes that typical TO-220/TO-247 heatsinking yields only **60–70 % of rated current at 40 °C ambient**. The IRF100B201's headline 192 A is not a real number. |

---

## 3. Current sensing

| Document | What it solves | Read |
|---|---|---|
| **INA240 datasheet** (SBOS662C, TI) · [PDF](https://www.ti.com/lit/ds/symlink/ina240.pdf) | The sense amp in the current BOM. CM range −4 V to +80 V (your 60 V bus fits), DC CMRR 132 dB, **AC CMRR 93 dB at 50 kHz**. | **§8.3.1.1** how the enhanced PWM rejection works. **§9.2.1** a worked inline motor current-sense design. |
| **SBOA174D** *Current Sensing in an H-Bridge* (TI, rev. Apr 2023) · [PDF](https://www.ti.com/lit/sboa174) | **The decision document for where to put your shunt.** | **Table 2 + Figure 3**: high-side vs. in-line vs. low-side, with explicit trade-offs. Note that low-side is cheap but **cannot detect a shorted load**. |
| **SBOA172** *Current Sensing for Inline Motor-Control Applications* (TI, Oct 2016) · [PDF](https://www.ti.com/lit/pdf/sboa172) | Why inline sensing is hard, and measured evidence that the INA240 handles it. | Read alongside SBOA174 **before** committing to inline sensing at 32 kHz. Also the source for the input RC filtering approach. |
| **Vishay doc 30405** *TCR for Current Sensing* (white paper, Rev. May 2020) · [PDF](https://www.vishay.com/docs/30405/whitepapertcr.pdf) | Shunt accuracy over temperature. | Key takeaway: at 1 mΩ the **copper terminations dominate TCR**, so spec the *component* TCR, not the element TCR. Also covers PCR self-heating drift and the Manganin/Zeranin/Evanohm comparison. |
| **Bourns e/N2210** *Using Current Sense Resistors for Accurate Current Measurement* · [PDF](https://www.bourns.com/docs/technical-documents/technical-library/current-sense-pulse-power-high-power-resistors/application-notes/bourns_n1702_current_sense_accurat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) | Practical Kelvin layout. | **Figures 3–6**, the four-wire connection geometry. This is the part people get wrong in KiCad. |

> **Not found:** a first-party resistor-vendor app note covering shunt **parasitic
> inductance (ESL)**. Bourns, Vishay and Isabellenhütte all cover Kelvin, TCR and
> self-heating but none address ESL. At 15–30 A with 32 kHz edges this matters; the
> mitigation (reverse-geometry or four-terminal metal-strip element + input RC filter) is
> covered in SBOA172 instead.

---

## 4. Inductive-load drive topology

| Document | What it solves | Read |
|---|---|---|
| **SLVA321A** *Current Recirculation and Decay Modes* (TI, rev. Apr 2021) · [PDF](https://www.ti.com/lit/pdf/slva321) | **The justification document for the topology choice.** The definitive short treatment of coast-vs-brake. | **§2.1 + Fig. 2-1** fast decay · **§2.2 + Fig. 2-3** slow decay · **§2.3 + Fig. 2-5** mixed decay. |
| **SLVAE59A** *Using Motor Drivers to Drive Solenoids* (TI, Apr 2022) · [PDF](https://www.ti.com/lit/pdf/slvae59) | The closest published analogue to driving an electromagnet coil. | **§3.1 peak-and-hold current control** — energize hard, then hold at low current to cut dissipation. Directly relevant to the 1800 W coil dissipation problem. **§2.1** freewheel/flyback paths, **§3.2** fast-discharge clamping. |

---

## 5. Bus protection

| Document | What it solves | Read |
|---|---|---|
| **Littelfuse MIDI HP, 70 V-SF36** bolt-down fuse · [PDF](https://www.littelfuse.com/assetdocs/littelfuse-datasheet-4998-midihp70v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) | **The correct fuse family for a 60 V DC bus.** 70 V DC, 30–200 A, 2500 A interrupting at 70 V DC, M6 bolt-down. | **Time-current curve, p. 3.** |
| **Littelfuse MIDI 32 V** bolt-down fuse · [PDF](https://www.littelfuse.com/assetdocs/midi-32v-bolt-down-series-data-sheet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) | ⚠️ **Included as a warning, not a recommendation.** | This is what dominates search results and it is **rated 32 V DC — do not use it on a 60 V bus.** DC interrupting capability does not extrapolate upward. |
| **Littelfuse TVS application note** (automotive SAD, ©2023) · [PDF](https://www.littelfuse.com/assetdocs/tvs-diode-sad-silicon-avalanche-diode-application-note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) | TVS selection method: standoff voltage, breakdown, clamping, peak pulse power. | **pp. 6–10** the selection methodology with SOA curves. Limitation: framed around automotive load dump, so the *method* transfers but the *pulse waveforms* do not — your pulse is the coil energy dump. |
| **Littelfuse 5.0SMDJ series** TVS datasheet (Rev. 4, 2026) · [PDF](https://www.littelfuse.com/assetdocs/littelfuse_tvs_diode_5_0smdj_datasheet.pdf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) | The numbers to actually pick a part. 5000 W at 10/1000 µs. | Full V_RWM / V_BR / V_C / I_PP table. **Fig. 2** power vs. pulse width, **Fig. 3** temperature derating. **5.0SMDJ70A** (V_R = 70.0 V) is the natural fit above a 60 V bus. |

> **Not found:** a Littelfuse **ANL** fuse datasheet. ANL is an Eaton/Bussmann style, not a
> Littelfuse series. The overview document's "125 A ANL/MIDI fuse" should become a MIDI HP
> 70 V part — and note that standard ANL fuses are commonly only rated 32 V or 80 V DC,
> which is a real problem on a 60 V pack that needs to interrupt a fault.

---
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

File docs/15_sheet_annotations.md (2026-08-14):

# `power_channel` — title block + on-sheet annotations

Copy-paste source. Everything below is meant to go **on the schematic**, not in a document.

Numbers in these blocks are all traceable: datasheet values verified this session
(IRF100B201 C_rss, V_GS(th); INA240 pinout; 5.0SMDJ package) or carried from
`09_design_sheet_rev0.md`.

---

## 1. Title block

File → Page Settings.

| Field | Value |
|---|---|
| **Title** | `Levitation Coil Drive — Power Channel` |
| **Company** | `Guadaloop — Levitation Subsystem` |
| **Date** | `2026-08-13` |
| **Rev** | `0` |
| **Comment 1** | `Full H-bridge, bidirectional coil drive. 60 V bus · 30 A design · ±45 A trip.` |
| **Comment 2** | `Instantiated twice. Rails on AUX_RAILS, connectors + buffers on IO_PROTECT, bulk caps on BUS.` |
| **Comment 3** | `PROVISIONAL — coil L, k and R are unmeasured. See assumption register on this sheet.` |
| **Comment 4** | `Design record: levpdu/09_design_sheet_rev0.md · review: levpdu/13_schematic_review_power_channel.md rev 1` |

**Change `Company` if that's not your team's name** — I took "Guadaloop" from a folder on
your Desktop, which is a guess, not something you told me.
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

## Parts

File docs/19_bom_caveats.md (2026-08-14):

# BOM caveats — where the schematic symbol is NOT the part to order

Rev 0 · 2026-08-14

KiCad's symbol libraries do not contain every part this design uses. In five places a
near-equivalent symbol was used and the **Value** and **MPN** fields carry the real part.
**Procurement must order by MPN, never by symbol name.** Three of these substitutions are
not cosmetic — ordering the symbol's part instead would break the design in a way that does
not show up until the board is powered.

| Ref | Symbol says | ORDER THIS | If you order the symbol's part instead |
|---|---|---|---|
| U6, U208 | `74xx:74LS132` | **74HCT132D,653** | **Breaks the safety interlock — see §1** |
| U4, U204 | `Comparator:LM393` | **LM2903BDR** | Part is only rated 0–70 °C on a 54 W board |
| U5, U205 | `74xx:74HCT74` ✓ | **74HCT74** | Do not accept a 74HC74 substitution — see §2 |
| U3, U203 | `Amplifier_Current:INA240A2D` ✓ | **INA240A2D** | Gain 50. An A1 (gain 20) makes every current reading 2.5× low |
| R11, R219 | `Device:R_Shunt`, value `0.5m` | **WSK2512L5000FEA** | 0.5 **milliohm**. A 0.5 Ω part would be a dead short's worth of error |

---

## 1. U6 / U208 — the one that matters most

The symbol is `74LS132` only because the KiCad library has no HCT variant of the quad
Schmitt NAND. **The part must be 74HCT132.**

74LS is bipolar TTL and its inputs *source* current when low: **I_IL = −0.4 mA**. R244, the
10 kΩ pulldown that makes the `EN` interlock default to OFF, cannot sink that:

    0.4 mA × 10 kΩ = 4 V

The pulldown would be completely defeated. **EN would float high, the board would power up
enabled, and the entire MCU shutdown interlock would be decorative.** The same current would
put 2 V across the RESET pull-up network and destroy the power-on-reset timing.

74HCT has ±1 µA input current, which is what makes 10 kΩ pulldowns and megohm-scale RC
timing work at all. It is also TTL-threshold (V_IH = 2.0 V), which is required because EN and
RESET arrive from a 3.3 V MCU into a 5 V-powered part.

**Do not accept 74HC132 either** — HC at 5 V needs V_IH = 0.7 × VCC = 3.5 V, above what a
3.3 V MCU delivers.

## 2. U5 / U205 — same threshold argument

74**HCT**74, not 74HC74. The design originally used HC and it was a finding: at VCC = 5 V an
HC part needs 3.5 V for a guaranteed HIGH, and the RESET line sits at 3.33 V.

## 3. U4 / U204 — temperature grade

The base LM393 is graded **0 °C to 70 °C**. This board dissipates ~54 W with eight TO-220s on
a common heatsink. LM2903B is pin-identical and graded −40 °C to +125 °C. The symbol name is
LM393 only because the library lacks an LM2903B entry.

Its supply is **+12 V, not +5 V** — that is deliberate. The LM2903B's input common-mode
ceiling is (V+ − 2.0 V) over temperature, and the 2.776 V trip threshold does not fit under a
5 V rail once the +5 V blocking diode's drop is counted. Outputs are open-drain and still
pull up to +5 V through R17, so nothing downstream changes.

## 4. R11 / R219 — read the value carefully

`0.5m` means **0.5 milliohm**, 4-terminal Kelvin, 1 %, 2512. This is a current-sense element
carrying the full coil current; a wrong value here is a wrong trip point and a wrong current
reading everywhere.

WSK2512 is rated **1.0 W at 70 °C** and dissipates 0.45 W at the 30 A design current.
**Do not substitute a 2-terminal part** such as WSLP2512 — the Kelvin connection is why the
board can use a 0.5 mΩ element at all.

---

## Connectors — board halves only; the harness needs its own line items

The schematic carries **only the PCB-side parts**. None of the mating hardware is in this BOM
and it must be added to the harness BOM or the boards arrive with nothing to plug into.

| Ref | Board part (in this BOM) | Harness side (NOT in this BOM) |
|---|---|---|
| J201 | Molex **43650-0400**, 1×4 Micro-Fit 3.0 header | 43645-0400 housing + 4 crimps |
| J202 | Molex **43045-1600**, 2×8 Micro-Fit 3.0 header | **43025-1600** housing + 16 crimps |
| J101, J203, J204 | Molex **38969-0002** ring-terminal block | ring lugs sized to the cable |

Note J202 changed from a 1×12 to a 2×8 on 2026-08-14. **Any harness already built to the old
12-way pinout is obsolete** — the pin assignment changed as well as the shell.

`43045` is the PCB header; `43025` is the wire-side receptacle housing. They are easy to
confuse and were confused once during this design.

---

## Capacitors

**C101–C106** — `100ZLH470MEFC16X31.5`, Rubycon ZLH, 470 µF 100 V, Ø16 × 31.5 mm.

The series matters. Rated ripple is **2.4 A rms at 105 °C / 100 kHz**, derating to about
**2.28 A at 16 kHz** by Rubycon's own frequency-correction table — roughly **13.7 A for the
bank of six**. A general-purpose series such as Nichicon UPW is only 1.31 A per can (7.9 A for
six), which does not cover the design. **Do not substitute on capacitance and voltage alone.**

There is no 470 µF / 100 V part in a Ø18 case in any mainstream series — that value only
exists at Ø16. Verify the **7.5 mm lead pitch** against Rubycon's own drawing before release;
it is the standard pitch for Ø16 but was not confirmed from the primary table.

All other capacitors carry a `Voltage` field. On a 60 V board that field is engineering
intent, not a purchasing detail — the bus bank and the bridge ceramics are ≥100 V and must
not be substituted downward.

## Resistors

R14, R15, R16 (and R218, R220, R221) set the over-current trip point and are specified
**1 %**. R11/R219 are 1 %. Do not accept 5 % substitutions on any of these six — they move
the trip point directly.

R101 is a **2512**, not a 1206. At 164 mW a 1206 sits at ~100 % of its derated rating beside
a hot heatsink, and a thick-film resistor at its limit fails **open, silently**, after which
the bus never bleeds.

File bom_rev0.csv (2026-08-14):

Reference | Qty | Value | DNP | Exclude from BOM | Exclude from Board | Exclude from Simulation | Exclude from Position Files | Footprint | Datasheet | Voltage
C1,C4,C16,C18,C226,C227,C230,C231 | 8 | 1uF |  |  |  |  | ${EXCLUDE_FROM_POS_FILES} | Capacitor_SMD:C_0805_2012Metric_Pad1.18x1.45mm_HandSolder |  | 25V
C2,C3,C11,C17,C20,C21,C22,C23,C204,C205,C206,C207,C208,C209,C210,C213,C217,C218,C223,C224,C225,C228,C229 | 23 | 100nF |  |  |  |  | ${EXCLUDE_FROM_POS_FILES} | Capacitor_SMD:C_0805_2012Metric_Pad1.18x1.45mm_HandSolder |  | 100V,25V
C5,C6,C7,C8,C12,C13,C14,C15,C212,C214,C215,C216,C219,C220,C221,C222 | 16 | 1uF |  |  |  |  | ${EXCLUDE_FROM_POS_FILES} | Capacitor_SMD:C_1210_3225Metric_Pad1.33x2.70mm_HandSolder |  | 100V
C19,C211 | 2 | 1nF |  |  |  |  | ${EXCLUDE_FROM_POS_FILES} | Capacitor_SMD:C_0805_2012Metric_Pad1.18x1.45mm_HandSolder |  | 50V
C101,C102,C103,C104,C105,C106 | 6 | 470uF |  |  |  |  | ${EXCLUDE_FROM_POS_FILES} | Capacitor_THT:CP_Radial_D18.0mm_P7.50mm |  | 100V
C201,C202 | 2 | 220uF |  |  |  |  | ${EXCLUDE_FROM_POS_FILES} | Capacitor_THT:CP_Radial_D8.0mm_P3.50mm |  | 25V
C203 | 1 | 10uF |  |  |  |  | ${EXCLUDE_FROM_POS_FILES} | Capacitor_SMD:C_1206_3216Metric_Pad1.33x1.80mm_HandSolder |  | 25V
D1,D3,D208,D209 | 4 | ES1D |  |  |  |  | ${EXCLUDE_FROM_POS_FILES} | Diode_SMD:D_SMA_Handsoldering
D2,D205 | 2 | 5.0SMDJ70A |  |  |  |  | ${EXCLUDE_FROM_POS_FILES} | Diode_SMD:D_SMC_Handsoldering
D4,D5,D6,D7,D203,D204,D206,D207 | 8 | 1N4148W |  |  |  |  | ${EXCLUDE_FROM_POS_FILES} | Diode_SMD:D_SOD-123
D201,D202 | 2 | SS34 |  |  |  |  | ${EXCLUDE_FROM_POS_FILES} | Diode_SMD:D_SMA_Handsoldering
F101 | 1 | 70A |  |  |  |  | ${EXCLUDE_FROM_POS_FILES}
J101 | 1 | +60V IN |  |  |  |  | ${EXCLUDE_FROM_POS_FILES}
J201 | 1 | RAILS IN |  |  |  |  | ${EXCLUDE_FROM_POS_FILES}
J202 | 1 | CONTROL |  |  |  |  | ${EXCLUDE_FROM_POS_FILES}
J203 | 1 | YOKE 1 |  |  |  |  | ${EXCLUDE_FROM_POS_FILES}
J204 | 1 | YOKE 2 |  |  |  |  | ${EXCLUDE_FROM_POS_FILES}
Q1,Q2,Q3,Q4,Q201,Q202,Q203,Q204 | 8 | IRF100B201 |  |  |  |  | ${EXCLUDE_FROM_POS_FILES} | Package_TO_SOT_THT:TO-220-3_Vertical | https://www.infineon.com/assets/row/public/documents/24/49/infineon-irf100b201-datasheet-en.pdf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
R1,R2,R9,R10,R214,R215,R226,R227 | 8 | 10R |  |  |  |  | ${EXCLUDE_FROM_POS_FILES} | Resistor_SMD:R_1206_3216Metric_Pad1.30x1.75mm_HandSolder
R3,R4,R6,R7,R14,R16,R17,R18,R19,R201,R202,R203,R204,R216,R217,R218,R221,R222,R223,R224,R225,R230 | 22 | 10k |  |  |  |  | ${EXCLUDE_FROM_POS_FILES} | Resistor_SMD:R_0805_2012Metric_Pad1.20x1.40mm_HandSolder
R5,R8,R231,R232 | 4 | 1R |  |  |  |  | ${EXCLUDE_FROM_POS_FILES} | Resistor_SMD:R_0805_2012Metric_Pad1.20x1.40mm_HandSolder
R11,R219 | 2 | 1m |  |  |  |  | ${EXCLUDE_FROM_POS_FILES} | Resistor_SMD:R_Shunt_Vishay_WSK2512_6332Metric_T2.66mm
R12,R13,R210,R211 | 4 | 10R |  |  |  |  | ${EXCLUDE_FROM_POS_FILES} | Resistor_SMD:R_0805_2012Metric_Pad1.20x1.40mm_HandSolder
R15,R220 | 2 | 24k |  |  |  |  | ${EXCLUDE_FROM_POS_FILES} | Resistor_SMD:R_0805_2012Metric_Pad1.20x1.40mm_HandSolder
R20,R21,R22,R23,R212,R213,R228,R229 | 8 | 4.7R |  |  |  |  | ${EXCLUDE_FROM_POS_FILES} | Resistor_SMD:R_0805_2012Metric_Pad1.20x1.40mm_HandSolder
R101 | 1 | 22k |  |  |  |  | ${EXCLUDE_FROM_POS_FILES} | Resistor_SMD:R_1206_3216Metric_Pad1.30x1.75mm_HandSolder
R205,R206,R207,R208,R209 | 5 | 100R |  |  |  |  | ${EXCLUDE_FROM_POS_FILES} | Resistor_SMD:R_0805_2012Metric_Pad1.20x1.40mm_HandSolder
U1,U2,U206,U207 | 4 | IR2184 |  |  |  |  | ${EXCLUDE_FROM_POS_FILES} | Package_SO:SOIC-8_3.9x4.9mm_P1.27mm | https://www.infineon.com/assets/row/public/documents/24/49/infineon-ir21844s-datasheet-en.pdf
U3,U203 | 2 | INA240A1D |  |  |  |  | ${EXCLUDE_FROM_POS_FILES} | Package_SO:SOIC-8_3.9x4.9mm_P1.27mm | http://www.ti.com/lit/ds/symlink/ina240.pdf
U4,U204 | 2 | LM393 |  |  |  |  | ${EXCLUDE_FROM_POS_FILES} | Package_SO:SOIC-8_3.9x4.9mm_P1.27mm | http://www.ti.com/lit/ds/symlink/lm393.pdf
U5,U205 | 2 | 74HC74 |  |  |  |  | ${EXCLUDE_FROM_POS_FILES} | Package_SO:SOIC-14_3.9x8.7mm_P1.27mm | https://assets.nexperia.com/documents/data-sheet/74HC_HCT74.pdf
U201,U202 | 2 | 74LVC2G17 |  |  |  |  | ${EXCLUDE_FROM_POS_FILES} | Package_TO_SOT_SMD:SOT-23-6 | http://www.ti.com/lit/sg/scyt129e/scyt129e.pdf

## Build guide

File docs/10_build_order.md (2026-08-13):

# Build Order — What to Draw, In What Sequence

Levitation coil drive stage · Sebastian · 2026-08-11
Companion to `09_design_sheet_rev0.md`

---

## 0. Workflow flag — read this before you start drawing

You said schematic in LTspice, then PCB in KiCad. **That's double work, and you don't have
time for it tonight.**

LTspice has no refdes management, no footprint assignment, no ERC, and no netlist export
KiCad can consume. Drawing 100 components there and then redrawing them in KiCad is two
full passes.

**Suggested instead:**

- **KiCad is the schematic of record.** Draw the real, complete schematic there — it's what
  feeds the PCB and what anyone reviews.
- **LTspice is for proving the blocks you're unsure of.** Four small sims, not a board:
  bridge + load, bootstrap hold-up, fault decay, OCP trip.

That's one pass plus four focused simulations, rather than two full passes. If your class or
your lead specifically requires an LTspice schematic, ignore this — but if it was just your
plan, this saves you hours tonight.

---

## 1. Two corrections to the design sheet

### 1.1 Logic buffer changed: **74HCT2G17**, not 74LVC2G17

The IR2184 datasheet gives **V_IH = 2.7 V minimum**. A 3.3 V logic high leaves only 0.6 V of
margin on a switching board — not enough.

**74HCT** has TTL-level inputs (V_IH = 2.0 V) on a 5 V supply. So it accepts a 3.3 V *or* a
5 V MCU and outputs a clean 5 V into the IR2184. That is a solid 2.3 V of margin over
threshold, and it makes the logic-level question genuinely irrelevant rather than
approximately irrelevant.

**Part: 74HCT2G17 (dual Schmitt buffer), supplied from 5 V.** You'll need a 5 V rail —
add a small LDO off the 12 V.

### 1.2 ⚠️ Two things you must verify yourself before placing anything

I pulled these from the datasheet PDF and I am **not confident in either**, because both come
from graphics rather than text:

**(a) The SD pin polarity.** I got "active HIGH for shutdown," but the IR2183/IR2184 family
differs on exactly this point between variants, and I've seen the opposite claimed. Getting
it wrong means either a permanently dead board or permanently defeated protection.

→ **Read the truth table on page 2 of the datasheet yourself.**
→ **And design around it:** bring the latch output to SD through a **strap-selectable
inverter** — a 74HCT1G14 that you can bypass with a 0 Ω link. Costs one part and a jumper,
and makes the polarity a build-time decision instead of a re-spin.

**(b) The pin numbering.** My extraction gave: 1 IN, 2 SD, 3 COM, 4 LO, 5 VB, 6 HO, 7 VS,
8 VCC. That VB/VS ordering looks wrong to me versus the usual IR2184 arrangement.

→ **Check the package drawing in the datasheet directly.**

This is worth taking seriously: the previous design's own open-items list flagged
*"cross-check every part's footprint pin-out against its datasheet — the one error class the
audits don't catch."* That was correct then and it's correct now. **Every footprint gets
checked against the package drawing, by eye, before layout.** Not against my text, not
against a KiCad library symbol.

**Confirmed good from the datasheet** (these came from tables, and they validate the design
sheet): V_BS UVLO rising **8.0–9.8 V** — the bootstrap calc stands. Deadtime **280–520 ns** —
adequate against ~200 ns turn-off.

---

## 2. Build order

Build the **atom first**, prove it, then replicate. Do not draw all four FETs and two drivers
and then try to debug.

### Step 1 — Sheet setup (15 min)

Hierarchical sheets: `POWER_CHANNEL` (×2), `AUX_RAILS`, `IO_PROTECT`.
Draw the channel once as a hierarchical sheet and instantiate it twice. Do not copy-paste —
you'll fix a bug in one copy and not the other.

Paste the §2 assumption register from the design sheet into a text block on sheet 1.

### Step 2 — One half-bridge + its driver ← **the atom**

Q1 (high) + Q2 (low) + one IR2184.

    VCC(12V) ──┬── C 1µF + 100nF ── COM
               └── D_boot(ES1D) ── R_boot(1Ω) ──┬── VB
                                                └── C_boot(1µF/25V) ── VS
    HO ── R_on 10Ω ∥ (R_off 4.7Ω + diode) ── Q1 gate
    LO ── R_on 10Ω ∥ (R_off 4.7Ω + diode) ── Q2 gate
    VS ── switch node (Q1 source / Q2 drain)
    COM ── power ground
    IN ── from 74HCT2G17 buffer
    SD ── from latch, via the strap-selectable inverter (§1.2a)

Add 10 kΩ gate-to-source pulldowns on both FETs — holds them off before the 12 V rail comes
up.

**Prove this in LTspice before going further.** Drive IN with a 32 kHz pulse, watch V_B − V_S
across the full duty range, confirm it never approaches the 9.8 V UVLO. This is the single
most useful sim you will run.

### Step 3 — Mirror to a full H-bridge

Second half-bridge, second IR2184, both across the same bus. Coil connects between the two
switch nodes.

**Both PWM inputs go to the connector independently** (design sheet §3.1). Resist the urge to
generate the second one on-board from the first — that's what locks you into a modulation
scheme.

### Step 4 — Bus network

2× 470 µF 100 V + 4× 1 µF 100 V 1210 + 4× 100 nF 0805, plus the 5.0SMDJ70A TVS.

**Layout note for later:** the ceramics go physically closest to the FET drains. The
commutation loop — bus cap → Q1 → Q2 → back to cap — is the highest-di/dt loop on the board
and it must be as small as possible. This matters more than almost anything else in the
layout.

### Step 5 — Current sense

1 mΩ 4-terminal shunt **in-line with the coil**, INA240A1 across it, REF pin at 1.65 V from
the 3.3 V rail via a divider + buffer (or a reference IC — a resistor divider alone will
drift).

Kelvin connections from the shunt sense terminals to the INA240 inputs, routed as a tight
differential pair. Small RC filter at the inputs.

### Step 6 — OCP + latch

LM393 as a window comparator: INA240 output vs. **2.55 V** and vs. **0.75 V**.
Open-collector outputs wire-OR with a common pull-up.

Into a **74HC74** as a set-dominant latch → strap-selectable inverter → both IR2184 SD pins.
Bring the latch output to the connector as `/FAULT`, and bring a reset line in.

**Do not skip the latch.** The old BOM had a bare LM393, which means the fault self-clears
the instant current drops and the bridge chatters into the fault repeatedly.

### Step 7 — Bus-fault detector → slow decay

This is design sheet §3.2 and it's the piece that makes the energy dump a non-problem.

Comparator on the bus voltage. On undervoltage or overvoltage: **drive both low-side FETs on**
rather than shutting everything off. Note this is *different* from the OCP path — OCP shuts
the bridge down, bus-fault commands slow decay.

**220 µF hold-up on the 12 V rail** so the FETs stay driven for the ~60 ms the current takes
to decay.

### Step 8 — Aux rails

LM5164 60 V → 12 V. Then 12 V → 5 V (buffers) and 12 V → 3.3 V (INA240, reference).
Mark the LM5164 DNF-able in case the pod supplies 12 V.

### Step 9 — Connectors

- Power (battery in, 2× yoke out): **Molex 38969-0002**, 50 A, 8–20 AWG
- Signals: the lead's Molex 0389220002, 20 A — fine here

Per channel: `PWM_A`, `PWM_B`, `/SD`, `ISENSE`, `/FAULT`, `RESET`, `AGND`, `DGND`.

---

## 3. The four simulations worth running

| # | Sim | Proves | Pass criterion |
|---|---|---|---|
| 1 | Bootstrap hold-up, duty 5–95 % | §4.3 sizing | V_B − V_S never below 10 V |
| 2 | Bus open at 30 A, both low FETs on | §3.2 | Bus stays under 100 V; current decays in <100 ms |
| 3 | Ripple, sign-magnitude vs. antiphase | Modulation sensitivity | Shows which scheme costs you |
| 4 | Shorted coil → OCP | Trip timing | Latch fires, bridge off, current bounded |

Sweep, don't confirm:

```
.param Rcoil=2  Lcoil=10m  kcpl=0.85  Vbus=60  Fpwm=32k
.step param Lcoil list 5m 10m 13m
```

If a result barely moves across that sweep, the design is insensitive to the thing you don't
know — which is the actual thing worth demonstrating tomorrow.

---

## 4. Suggested time budget

| | |
|---|---|
| Sheet setup + assumption block | 15 min |
| Half-bridge atom + sim 1 | 1 h |
| Mirror to H-bridge | 20 min |
| Bus network | 20 min |
| Current sense | 45 min |
| OCP + latch | 45 min |
| Bus-fault → slow decay | 30 min |
| Aux rails | 30 min |
| Connectors + IO | 30 min |
| Second channel (instantiate) | 10 min |
| Sims 2–4 | 1 h |
| **Total** | **~6 h** |

Doable. **If you run short, drop sims 3 and 4 and the bus-fault detector** — the fault
detector is a genuine improvement but it's the piece you can add in rev 1 without disturbing
anything else.

---

## 5. What to tell your lead tomorrow

Lead with what makes this defensible rather than with what's unresolved:

1. **Topology derived, not inherited** — H-bridge justified from the confirmed PM-biased
   HEMS architecture, with the simpler alternative documented and ruled out on evidence.
2. **Three unknowns designed around rather than guessed** — independent PWM inputs make the
   modulation scheme irrelevant, HCT buffers make the logic level irrelevant, and
   slow-decay-on-fault makes the inductance irrelevant to protection.
3. **A real defect found and fixed** — the previous BOM's over-current comparator had no
   latch and would chatter into a fault.
4. **A connector conflict caught before layout** — the EDD specifies 10 AWG, the specified
   part accepts 12 AWG max at 20 A. Resolved with Molex 38969-0002 at 50 A, same family.
5. **One open risk, stated plainly** — if the coil is 4 Ω rather than 2 Ω the gate drive
   needs rework. Independent calculation from the coil geometry says 2 Ω. One measurement
   closes it.

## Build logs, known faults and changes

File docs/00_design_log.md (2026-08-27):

# Levitation Coil Drive Stage — Engineering Design Log

**Engineer:** Sebastian
**Project:** Hyperloop pod levitation power/drive electronics
**Started:** 2026-08-11
**Approach:** Manual design. Schematic drawn in LTspice, PCB in KiCad. Every parameter
sourced or measured; nothing assumed.

---

## Why this log exists

A prior revision of this board was produced with AI-assisted placement and auto-routing.
It passed ERC, DRC and a net-by-net audit. It was still rejected — not because a check
failed, but because passing checks is not the same as understanding a design, and a board
you cannot defend is a board you cannot bring up on the bench.

This rebuild is deliberately slower. This log records what was decided, what was rejected,
and why — including the things that turned out to be wrong.

---

## Index of documents

| # | Document | Status |
|---|---|---|
| 00 | Design log (this file) | living |
| — | Open questions & first-pass review | **issued 2026-08-11, awaiting answers** |
| 01 | Reference library — verified datasheets, app notes, reference designs | rev 0 |
| 02 | Drive topology derivation | rev 0 — conditional on Q4 |
| 04 | Board partitioning — one board or two, and is a PDU needed | rev 0 — conditional on Q1, Q17 |
| 06 | HEMS slide + LEV EDD findings — **includes retractions of three Day-1 findings** | rev 1 |

---
- `16_adversarial_review.md` — hostile review of the full schematic, 19 findings, datasheet-verified
- `17_rev0_fix_plan.md` — the executable fix list: 7 blocks, ~19 new parts, ~3 hours
- `18_firmware_interface.md` — MCU-side contract: pinout, EN, OK polarity, scaling, sequences
- `19_bom_caveats.md` — where the symbol name is NOT the part to order

## 2026-08-11 · Day 1

### Inputs received
- `Levitation_Power_System_Overview.pdf` — prior design overview, 2 control boards + PDU
- `more_constraints.txt` — transcript of the requirements conversation with the lev team
- Verbal constraint from lead: Molex 0389220002 barrier strips for external connections

### What I did
Read both documents, extracted every stated parameter into a table with a provenance
column, and ran a first-pass operating-point calculation before accepting any of the
prior design's conclusions.

### Findings — the design is structurally sound but rests on unverified numbers

**Confirmed correct in the prior design.** Not everything needed changing:
- INA240 for current sense — its enhanced PWM common-mode rejection is exactly the right
  tool for in-line shunt measurement on a switching bridge leg, and its offset is low
  enough that 1 mΩ still resolves the sub-1 A baseline.
- Ripple analysis — 188 mA pk-pk at 16 kHz / D = 0.5, i.e. 0.6 % of 30 A. The prior
  document's 0.6 % figure checks out independently.
- Diagonal yoke pairing (FL+RR / FR+RL) — the failure-mode reasoning is sound.
- Freewheel rather than active reversal for current decay — correct, and it is what keeps
  the bus overvoltage problem (below) from being worse than it is.
- Centralising pack protection in a separate PDU — right call.

**Structural finding: 30 A/yoke is exactly 100 % duty cycle, not a peak.**
`I_max = V/R = 60 V / 2 Ω = 30.0 A`. τ = L/R = 2.5 ms is ~40 PWM periods, so the load is
resistance-dominated and the inductance never lets current exceed V/R. There is no
transient headroom above 30 A. Two consequences the prior design did not account for:
- The specified 45 A over-current trip **can never fire in normal operation**. It is a
  fault detector only, and must not be mistaken for coil thermal protection.
- 100 % duty is **incompatible with a bootstrap high-side gate supply**. The bootstrap
  capacitor only recharges while the low side conducts. Practical ceiling is ~95–98 %
  duty, i.e. ~28.5–29.4 A. Quantified in Infineon AN-1123 §2.2.

**Blocking conflict: the peak current target differs by 2× between the two source documents.**
Lev team said "minimum is like 60 A total across 4 yokes" (15 A/yoke). The overview
document specifies 30 A/yoke, 120 A total. This one number sets the connector, the wire
gauge, the PDU copper, the heatsink, the FET count and whether the gate drive works at
all. Design cannot proceed past block diagram until it is fixed.

**Largest unanswered risk: coil thermal survival.**
At 30 A/yoke the coil dissipates `I²R = 1800 W` per yoke — 7.2 kW across the pod. At
15 A/yoke it is 450 W / 1.8 kW. The overview document calls this a "brief peak during
disturbances" but nothing in the hardware bounds the duration. Nobody has stated how long
a coil survives at peak. Issued to the lev team as Q3.

**Coil energy dump can exceed the 100 V device ratings.**
At 30 A a yoke stores `½LI² = 2.25 J`. Dumped into the 470 µF bus cap alone (battery
disconnected, fuse open, connector bounce) the bus reaches 115 V — above both the
IRF100B201 and the bus caps. At 15 A it reaches 77 V, which is fine. So at the higher
current target the design's survival depends on the battery being connected, which makes
the battery connection safety-critical rather than merely functional. Needs an explicit
clamp/bleeder answer.

**The lead's connector is rated 20 A.**
Molex 0389220002 verified from the manufacturer: 20.0 A max per contact, 300 V, AWG 12–26.
Marginal at 15 A/yoke (75 % of rating), fails at 30 A/yoke, and nowhere near the 60–120 A
battery path. AWG 12 is also the largest wire it accepts. Raised with the lead as Q10 with
four resolution options rather than a flat objection.

**PDU copper needs computing, not assuming.** IPC-2221 first pass for 2 oz external:
60 A needs 18–28 mm width; **120 A needs 48–73 mm**. The PDU board is 120 × 80 mm, so at
120 A essentially the entire board must be uninterrupted bus copper — while the fuse
holder, TVS and connectors all interrupt it. Marginal at best.
*Later correction: this used IPC-2221, which is now known to model a conductor in free
air. To be re-derived against IPC-2152 data.*

**Also flagged:** XT60 at 60 A/board has zero margin (rated 60 A); a 125 A ANL fuse does
not open until ~200 A+ and so does not protect a 120 A load; and standard ANL/MIDI fuses
are commonly rated 32 V DC, which is invalid on a 60 V pack.

### Decision: re-derive the topology rather than inherit it
The prior design specifies a full H-bridge per yoke. Rather than validate it on its own
terms, derive the topology from the load and control requirements. If the H-bridge is
right it will fall out of the derivation and be defensible; if it is not, better to know
before layout. → document 02.

### Result of the derivation — a requirement nobody had written down

Force on an attractive electromagnet goes as B², so **current direction does not affect
force** for a pure electromagnet. Bidirectional current is only meaningful if the
suspension is permanent-magnet biased. The overview document asserts PM bias; the lev
team never confirmed it. Issued as Q4.

But the more interesting finding is that **negative voltage and negative current are
separate requirements**, and the prior design conflated them. Slow-decay di/dt is `−I·R/L`,
which goes to zero as current goes to zero — so a freewheel-only drive is *least* able to
reduce current exactly where this system normally operates:

| Operating point | Rise rate | Slow-decay rate | Asymmetry |
|---|---|---|---|
| 1 A (the ideal baseline) | +11.6 A/ms | −0.4 A/ms | **29 : 1** |
| 5 A (the stated baseline) | +10.0 A/ms | −2.0 A/ms | 5 : 1 |
| 15 A | +6.0 A/ms | −6.0 A/ms | 1 : 1 |

A PID loop driving a plant that responds 29× faster in one direction than the other will
either be detuned to the slow direction or will overshoot persistently. **So the drive
needs a −V capability regardless of whether the current ever reverses sign.**

That produces a clean decision rule instead of an assumption:

- **PM-biased (current must reverse)** → full H-bridge, 4 switches — as originally specified
- **Not PM-biased (current unidirectional, but still needs fast decay)** → **asymmetric
  half-bridge**, 2 switches + 2 diodes, giving the full +V / 0 / −V control set with half
  the switches and half the gate drivers

The original H-bridge is not *wrong* — it is a superset that works either way. But if the
suspension is not PM-biased it carries twice the switches, twice the drivers, twice the
conduction loss and twice the failure modes for a capability that is never used.

### Secondary finding: the natural current bandwidth may be too low
`f_c = 1/(2πτ) = 63.7 Hz`. For a levitation loop — open-loop unstable, and wanting a
current loop several times faster than the position loop — 64 Hz is not obviously enough.
This is the strongest argument for the current sensing the lev team was ambivalent about:
an inner current loop with voltage overdrive can push effective bandwidth well above the
natural 64 Hz, but only if the current is measured. Issued as Q3/Q9.

### Also raised with the controls team
Arduino PWM at 16 kHz on a 16 MHz AVR gives ~8–10 bit resolution. At 8 bit, one LSB =
60 V/256 → **117 mA of coil current**, leaving roughly 8 usable steps to hold a sub-1 A
baseline. This may be a control-resolution problem before it is a hardware problem.

### Reference library assembled
Verified first-party documents for every design block — gate drive, MOSFET loss and
thermal, current sensing, decay modes, bus protection, PCB copper. Aggregator sites
rejected. Four requested items could not be verified on a manufacturer domain and are
recorded as *not found* rather than substituted. Two published TI reference designs
(TIDA-00365 for voltage class, TIDA-00620 for current density) match closely enough to be
worth reading in full. → document 01.

### Open at end of Day 1
- **Blocking:** peak current target (Q1), measured L and R (Q2), coil thermal limit (Q3),
  bidirectional requirement (Q4), series-vs-parallel coils (Q5), max charged pack voltage (Q6)
- **Blocking:** connector resolution with lead (Q10)
- **Next once unblocked:** shunt placement decision from SBOA174; bootstrap sizing from
  AN-1123; FET loss and heatsink budget from AND9083 + AND8220; re-derive PDU copper
  against IPC-2152

---

## 2026-08-11 · Day 1, later — the overview document is downgraded from requirements to hypothesis

Confirmed with Sebastian that the "permanent-magnet biased suspension" claim in the
overview PDF was **likely AI-generated**, not stated by the lev team.

This is the most consequential finding so far, and not only for that one sentence. It
means the overview PDF is a **design output with rationale back-filled onto it** — its
"requirements" sections read like requirements but were partly reconstructed to justify
decisions already taken. The claim in question was the *entire* stated justification for
choosing a full H-bridge.

**Working rule from here:**
- `more_constraints.txt` is authoritative — it is a transcript of humans stating requirements.
- The overview PDF is a hypothesis. Every claim needs a source before it is designed against.

Claims now carrying UNVERIFIED flags: PM bias; "brief peaks up to 30 A"; "a lost diagonal
keeps remaining support roughly balanced"; the 45 A trip; 2 Ω / 5 mH per yoke.

Worth recording that this is *not* a reason to distrust the prior work wholesale — the
ripple analysis, the freewheel decay choice and the INA240 selection all held up under
independent check. It is a reason to source each claim before building on it.

### Board partitioning analysed → document 04

Established that **the board-count question and the PDU question are the same question**:
a PDU exists only to split the pack between multiple drive boards. One 4-channel board
needs no PDU.

Decisive factor is bus current, which is set by yoke current and channel count and is
independent of the topology choice: 4 channels at 15 A/yoke is 60 A (comfortable on a
PCB); 4 channels at 30 A/yoke is 120 A (a hard PCB problem). So board count is downstream
of Q1, plus pod geometry (new Q17).

Provisional recommendation: **two identical 2-channel boards** — but justified on bus
current, assembly risk and re-spin blast radius, **not** on the fault-tolerance argument
the overview PDF gave. That argument rests on the unverified premise that a pod is
controllable on two yokes at all; if it isn't, "which two yokes you lose" is irrelevant.
Issued as Q16 rather than inherited.

Noted a factor the prior design did not: four current measurements feeding one controller
share one clean analog ground on a single board, whereas across two boards the INA240
outputs are referenced to grounds carrying 30–60 A of switching current. At 1 mΩ, 1 A of
coil current is 1 mV — tens of millivolts of inter-board ground offset is not negligible.
Solvable via the INA240's REF pins, but it is design work the one-board option avoids.

### Recommendation: buy the PDU rather than build it

The PDU contains no switching and no control — it is a fuse, a TVS, a precharge resistor
and copper. Carrying 60–120 A on a PCB is among the harder problems in this project and a
solved commercial problem in 48 V marine/solar power distribution.

Verified that the **Victron MEGA-fuse is available in an 80 V DC variant covering
40–500 A**, which spans both candidate current targets with real headroom over a 60 V
pack. This also resolves the separate problem flagged earlier that standard ANL and MIDI
bolt-down fuses are commonly rated 32 V DC and are invalid on a 60 V bus.

Caveat carried forward: most commercial automotive/marine distribution blocks are rated
≤ 48 V DC. The voltage rating of every candidate part must be checked, and DC interrupting
capacity does not extrapolate upward from a lower-voltage variant — there is no zero
crossing to help extinguish a DC arc.

### New open questions
- **Q16** (lev/controls) — is the pod controllable on two yokes at all?
- **Q17** (lev/mech) — pod dimensions and physical yoke locations relative to the electronics
- **Q18** (Sebastian/lead) — is buying a commercial distribution block instead of
  fabricating a PDU acceptable? Right engineering call, but it removes a board from a
  project that may be assessed on what was built.

---

## 2026-08-11 · Day 1, evening — two real source documents surface, and I retract three findings

Sebastian produced a team slide ("Main Objective & Principle") and **LEV EDD 2026 1.pdf**.
These are proper team engineering documents and they supersede both the overview PDF and
much of the chat transcript. Full analysis in document 06.

### Q4 answered — and the "AI-generated" claim turns out to be correct

The system is **HEMS: Hybrid Electromagnetic Suspension** — permanent magnets providing
constant attractive force, coils actively regulating. The EDD's Fig. 3 plots force vs. gap
for **I = −16 A to +12 A**, which settles it: **current is bidirectional, the full H-bridge
is the right topology.** Document 02's decision rule resolves to the H-bridge branch.

Worth recording honestly: the PM-bias claim in the overview PDF — the one flagged this
morning as possibly AI-generated — is **correct**. It was unsourced, not wrong. That
distinction is exactly why the process was to verify rather than discard. The other flagged
claims remain unverified.

### The Q1 "conflict" was never a conflict

"60 A total" (chat) and "120 A total" (overview PDF) are both straight from the EDD table:
60 A is *Max Continuous Current*, 120 A is *Peak Current Capability*. Nobody was wrong and I
had spent the morning treating it as a blocking contradiction.

### The coil resistance conflict — settled by independent calculation

EDD says **2 Ω/coil**; the chat said 4 Ω. Rather than pick one, checked it against the
physical coil spec (250 turns of 18 AWG, yoke 228.6 × 76.2 × 127 mm). 18 AWG is 20.95 mΩ/m,
so 250 turns at a 300–400 mm mean turn gives **1.6–2.1 Ω cold**. The EDD is geometrically
consistent; 4 Ω would need a ~750 mm mean turn the envelope doesn't allow.

**Working value 2 Ω/coil → 1 Ω/yoke, still to be confirmed by measurement.**

### RETRACTIONS

Three of this morning's findings were built on the chat's 4 Ω figure and do not survive:

- ❌ **"30 A/yoke is exactly 100 % duty with no headroom."** With R_yoke = 1 Ω the ceiling is
  **60 A/yoke**; 30 A needs only 30 V, i.e. **50 % duty** — matching the EDD's stated 50 %
  limit. There is **30 V of headroom** at the peak operating point.
- ❌ **"100 % duty breaks the bootstrap high-side supply."** At 50 % duty the bootstrap
  recharges every cycle. Routine sizing, not a structural flaw.
- ❌ **"The 45 A over-current trip can never fire."** With a 60 A ceiling it is reachable and
  is real protection.

The design's operating point is materially better than the one I analysed this morning.
Recording this in full rather than quietly correcting it — the reason the chat numbers were
wrong is that they came from someone who prefaced them "I highkey don't remember," and the
lesson is that a remembered number and a documented number are not the same input.

### What survived

The connector conflict (worse — see below), the 120 A of PDU copper, the fast-decay
requirement, the fuse voltage-rating problem, and large coil dissipation (now 900 W/yoke,
3.6 kW total — half my earlier figure, still substantial).

### New: the 18 AWG thermal claim checks out

EDD §2.3 claims 18 AWG (rated 7 A continuous) safely absorbs 15 A peaks. 15 A in 0.823 mm²
is **18.2 A/mm²**, which looked optimistic, so I checked the transient rather than the
steady state. Copper mass ≈ 0.55–0.74 kg/coil → thermal mass 213–284 J/K; at 450 W/coil that
is **1.6–2.1 K/s, i.e. 47–63 s to +100 K**. **The claim holds if "brief" means seconds.**
Good reasoning on their part. Q3 narrows from an open unknown to "where between 1 s and 60 s."

### New: an error in EDD §2.2

The EDD justifies parallel coils by saying series would require **120 V**. That assumes 30 A
through the series pair, but force depends on MMF = N·I *per coil*, so series needs the same
15 A per coil — **60 V, not 120 V**. The conclusion (parallel) is still right, but for a
different reason: series at 60 V sits at 100 % duty with zero headroom, parallel at 30 V sits
at 50 % with 30 V spare. Worth correcting because the stated reasoning would mislead if the
bus voltage ever changed.

### New: mutual inductance, and a result that simplifies one decision

Both coils sit on the same magnetic circuit, so M = k·L is significant. Derived that
**τ = L(1+k)/R is identical for series and parallel** — series/parallel changes current
capability, not speed. That removes one variable from that trade-off.

Consequence for Q2: measuring one coil in isolation is insufficient. Need one coil with the
other **open** (gives L) and with the other **shorted** (gives L(1−k²)) — two readings give k.

### REVISED AND WORSE: the coil energy dump

The higher parallel-yoke inductance makes this worse, not better. At 30 A with L_yoke ≈
9.25 mH the coil stores **4.16 J**; dumped into the 470 µF bus cap with the battery absent
the bus reaches **146 V** against 100 V parts (my morning figure was 115 V). Holding it below
85 V on capacitance alone would need ~2300 µF per yoke.

The battery normally absorbs this, so the real fix is a sized TVS plus adequate bulk plus
never opening the bus under load — but **the 470 µF in the BOM was clearly not chosen with
this calculation behind it**, and the triggering fault (fuse opens or connector bounces at
peak) is plausible on a pod.

### Connector conflict is now dimensional, not a judgement call

EDD §2.2 specifies **10 AWG** conductors to the yokes. The Molex 0389220002 accepts
**AWG 12–26** and is rated **20 A**. The wire will not physically fit, and the part is rated
at two-thirds of the required current. This must be resolved with the lead before any
footprint is placed.

### Plant dynamics, now from their numbers

316 kg pod, 8 mm nominal gap, ~3100 N (internally consistent: 316 × 9.81 = 3100).
Unstable pole from the Fig. 3 force–gap slope ≈ **30.8 rad/s (4.9 Hz), 32 ms to double** —
considerably more benign than the 1–2 mm gap I had assumed this morning. Current-loop
separation lands at **2.7–3.5×** at the likely inductance: tight against the 5–10× rule of
thumb but not disqualifying, especially with 30 V of headroom to overdrive with.

### New open questions
- **Q22** — is 30 A/yoke a physics requirement, or inherited from the 30 A motor drivers
  being replaced?
- **Q23** — where does the 50 % duty limit come from: thermal, control, or the existing driver?
- **Q24** — is the EDD current? Does it describe the yoke on the pod today?

---
*Log continues.*

---

## 2026-08-12 — `power_channel` schematic review (netlist-level, not visual)

Reviewed the completed `power_channel` sheet. Rather than inspect the drawing, I parsed
`power_channel.kicad_sch` directly and rebuilt the connection graph from raw geometry —
symbol origins, library pin offsets, KiCad's rotation and mirror transforms, wire
segments, junctions, labels and power symbols — and extracted the netlist independently
of KiCad. 54 components, 142 wires, 57 junctions, 36 labels.

Full findings in `13_schematic_review_power_channel.md`.

### The drawing is geometrically clean

No dangling wire ends, no labels attached to nothing, no wires crossing without a needed
junction and none crossing with an unwanted one, no floating pins except the two the
no-connect flags cover. For a hand-drawn 142-wire sheet that is a good result and worth
recording, because the errors that *were* found are design errors, not drafting errors.

### One blocking error: the LM393 supply is reversed

`U4` unit 3 is rotated 90°, and after the rotation pin 8 (V+) lands on the GND symbol
while pin 4 (V−) lands on the +5 V wire. The comparator is powered backwards: it does not
work, it conducts through its ESD structures, and the over-current protection is silently
dead — `FAULT_N` floats high, the latch never sets, the bridge keeps switching.

**ERC will not catch this.** It reports "power input not driven" on both rails (correct,
since the rails are generated on a sheet that does not exist yet), and the swap hides
inside a message that is expected and will be dismissed.

Method note, because it matters: this hinged entirely on KiCad's 90° transform, and both
candidate sign conventions place the pins on wires, so geometry alone is ambiguous for
any two-pin part. It was resolvable only because the LM393 power unit's two pins share a
library x-offset, which forces them to share a y after rotation — and only one convention
puts that y at 59.69, where the GND symbol and the +5 V wire end actually sit. Fetched
copies of the KiCad source disagreed with each other on this, so the file itself had to
settle it. Same class of ambiguity as the IR2184 pinout mistake; caught this time.

### Quantified: the bulk capacitors cannot carry the ripple

Previously logged as "electrolytic ripple-current ratings unverified". Now closed with a
number. At 30 A and D ≈ 0.5 the bus sees **15 A RMS per channel**. At 32 kHz the two
470 µF electrolytics present ~25 mΩ against the eight 1 µF ceramics' ~620 mΩ, so the
electrolytics take **~14 A of it into parts rated about 2 A each**.

Adding ceramic does not fix it — matching 25 mΩ at 32 kHz needs ~190 µF of 100 V ceramic
before DC-bias derating. The answers are more electrolytics (6×), polymer/hybrid parts
(3–4×), or a lower real design current. Interleaving the two channels cancels ripple on
the shared bus but not in each channel's local commutation loop, so it cannot be used to
size these parts.

### The OCP path contradicts §3.2 of the design sheet

§3.2 says: on a fault, turn both low-side FETs **on** so the coil dumps into its own
resistance. The drawn OCP pulls `SD` low, which tri-states both half-bridges — a hard
turn-off, the one action §3.2 exists to prevent. The coil then freewheels through the
body diodes into the bus: 9.4 J at the 45 A trip, reaching 153 V into 940 µF if the bus
happens to be isolated.

The battery normally absorbs it. But an over-current is a plausible *cause* of a blown
fuse, so the trip and the isolated-bus condition are correlated, not independent.

Two options recorded: accept for rev 0 and log the limitation, or gate the PWM inputs
with the latch's Q̄ through a 74HC08 — which turns a fault into slow decay directly,
leaves `SD` high, and makes the OCP path and the bus-fault path behave identically. One
part. **Decision still open.**

### Design sheet vs. schematic drift

Two §4 items did not make it into the drawing:

- **§4.3 gate turn-off network** (4.7 Ω + parallel diode) — absent; gates have a single
  symmetric 10 Ω. Matters in an H-bridge because of dv/dt-induced turn-on through C_gd.
- **§4.5 shunt** — §4.5 says explicitly "not a 2512 thick film"; `R11` is committed to
  `R_2512_6332Metric`. 2.0 W at the 45 A trip against a 1 W part, plus a thick-film TCR
  that walks the trip point.

Either build them or amend §4. A design document that quietly disagrees with the
schematic is worth less than no document.

### Smaller findings

- INA240 input filter is 10 Ω + 1 nF → **7.96 MHz** corner. Effectively no filter. Not
  wrong (TI SBOA174 argues against heavy input filtering, which unbalances the CMRR the
  part depends on) but it should not be described as a filter.
- No bus bleed resistor. 940 µF at 60 V = **1.7 J** persisting after power-down on a
  board people will probe.
- Single `GND`; §3.1 lists AGND and DGND separately. Defensible for rev 0, but a decision.
- Missing footprints on U5, C19, C20, R12, R13. No voltage rating field on any capacitor —
  the most dangerous BOM omission on a 60 V board. No tolerance field on the three
  resistors that set the trip point.
- All seven hierarchical labels are typed `input`; COIL_A/COIL_B are passive and
  ISNS/FAULT are outputs.

### Confirmed correct against first-party datasheets

INA240 pin 4 verified against TI SBOS662: "Reserved. Connect to ground or leave floating"
— tying it to GND is permitted, and my earlier sketch saying "leave open" was equally
valid, not a correction. Threshold divider maths, comparator polarity (crossed inputs
giving OR through the wired-AND), latch set-dominance and power-on state, Q̄→SD, the SD
pulldown direction, both bootstrap diode orientations, the TVS cathode, the electrolytic
polarity, and gate pulldowns returned to their own sources — all verified correct from
the extracted netlist.

Worth noting one property of the design that emerged from the review rather than being
designed in: both trip thresholds and the INA240's 1.65 V mid-scale come from the same
3.3 V rail, so the trip current is ratiometric and rail error cancels instead of shifting
the trip point.

### Project file hygiene — a real risk, not housekeeping

The root sheet's `Sheetfile` property points at `..\..\Downloads\power_channel.kicad_sch`.
The live schematic lives in Downloads, outside the project folder, while two stale copies
(37 symbols and 24 symbols) sit inside `final_lev\` where they can be loaded by mistake.
Recovery procedure recorded in the review document.

---
*Log continues.*

---

## 2026-08-13 — RETRACTED: the LM393 supply reversal

**Yesterday's blocking finding was wrong. There is no error. U4 pin 8 (V+) is on `+5V`
and pin 4 (V−) is on `GND`, which is correct.** Sebastian caught it by looking at the
schematic; I had it from a reconstruction that was confidently, self-consistently wrong.

### Root cause

The whole netlist-extraction approach depends on getting KiCad's symbol rotation matrices
right. For `(at x y 90)` the library-to-sheet mapping is one 2×2 matrix. I solved for it
empirically — tried candidates, kept the one that made pins land on wires.

I compared the wrong pair:

    (0, 1, 1, 0)    det = −1     legal
    (0, 1, −1, 0)   det = +1     inadmissible

and chose the second, because under it U4's pins landed exactly on the +5 V wire end and
the GND symbol while under the first they floated. The evidence was real. The hypothesis
was impossible.

Every unmirrored placement in KiCad is the default transform `(1, 0, 0, −1)` — det −1,
because library Y is up and sheet Y is down — composed with a pure rotation, det +1. The
product must have **det −1**. Det +1 is a mirrored placement, and the file states U4 is
not mirrored. One line of arithmetic kills my answer.

The two legal 90°-family candidates are `(0, 1, 1, 0)` and `(0, −1, −1, 0)`. I never
tested the second because I had it filed under 270°. Correct mapping:

    0° → (1, 0, 0, −1)    90° → (0, −1, −1, 0)    180° → (−1, 0, 0, 1)    270° → (0, 1, 1, 0)

### The lesson, which is the part worth keeping

**Constraints before evidence.** I ranked hypotheses by how well they explained the data
without first checking whether they were physically admissible. The determinant test is
free and deletes an entire branch before any weighing starts. I did the expensive step
first and skipped the cheap one.

Two failure modes stacked on top of each other here:

1. I had already been burned on the IR2184 pinout by trusting a rendered datasheet page,
   so I over-corrected into "derive everything from raw geometry" — and then applied that
   method without its own sanity check.
2. Two independent web fetches of the KiCad source disagreed with each other on these
   matrices (one returned a 180° case that was not even a rotation). Having decided both
   were unreliable, I fell back on empiricism and treated the file as ground truth,
   forgetting that the file is only ground truth once the *reader* is correct.

`08_honest_assessment.md` says: *a design that is internally consistent and externally
wrong passes every check you can run on it.* That was written about the design. It
applies just as well to the analysis. My reconstruction was internally consistent under a
transform that cannot exist, and it stayed that way until a human looked at the screen.

### Scope of the retraction

Re-ran the extraction with corrected matrices and diffed against the previous run. **One
substantive change: U4 pins 4 and 8.** Every other delta is a pin-number swap on a
symmetric two-terminal part — resistors and non-polarised capacitors — where net
membership is identical and only the 1/2 labelling flips.

The only polarised parts at 90° or 270° are U4 unit 3 and D2. D2 re-checks correct
(cathode on `+60V`), but that now wants confirmation by eye rather than by my arithmetic.

Also cleared: with the corrected matrices, zero power symbols resolve as floating.

Unaffected, because none of it depends on rotation: the bus ripple-current calculation,
the OCP hard-off vs. slow-decay question, the missing gate turn-off network, the shunt
type, the INA240 input filter corner, the bleed resistor, the AGND/DGND decision, and all
of the housekeeping items. The schematic review is reissued as rev 1.

### Standing note

Second time Sebastian has overruled me on a KiCad connectivity claim and been right both
times. Recording that as a process fact, not a pleasantry: on anything that can be read
directly off the canvas, **his eyes are the instrument and my reconstruction is the
model.** When they disagree, the model is what gets re-derived first.

### File hygiene — resolved

`Desktop\final_lev\` is now self-contained. The live 58-symbol sheet is in the project
folder, the root sheet's `Sheetfile` property points at it locally instead of at
`..\..\Downloads\`, and the two stale copies are parked in `_old\` under names that make
them unmistakable. A pre-edit backup of the root sheet is in `_old\` as well.

---
*Log continues.*

---

## 2026-08-13 — `power_channel` closed out. ERC clean.

Sheet is finished: 62 components, 44 labels, all footprints assigned, title block and
nine on-sheet annotation blocks in place. ERC returns 12 errors and 6 warnings and
**every one of them is expected** — nothing on this sheet needs changing.

### ERC results, accounted for line by line

| Count | Message | Why it is expected |
|---|---|---|
| 7 err | `pin_not_connected` — all seven sheet pins on the root | The root sheet holds one sheet symbol and nothing else. Resolves when `IO_PROTECT` exists and the root gets wired |
| 5 err | `power_pin_not_driven` — +60V, +12V, +5V, +3V3, GND | PWR_FLAGs belong on `AUX_RAILS`, which does not exist yet. Deliberately not silenced here |
| 3 warn | `isolated_pin_label` — FAULT, PWM_A, PWM_B | Same root cause as the seven. These three hierarchical labels touch exactly one pin inside the sheet; the other four touch several |
| 2 warn | `pin_not_driven` — U1.1, U2.1 (IN) | The PWM inputs have no driver yet. Buffers are on `IO_PROTECT` |
| 1 warn | `multiple_net_names` — SW_B / COIL_B | Intentional. Half-bridge B's switch node *is* the coil B terminal, because the shunt is only in the A leg |

**ERC also settled an open question for free.** Five distinct `power_pin_not_driven`
violations means five distinct undriven power nets — which confirms `+60V` and `+12V`
are separate nets despite `#PWR01` being a `power:+12V` symbol with its Value edited.
Had they merged there would have been four. That closes the item without hovering
anything.

**On the `isolated_pin_label` warnings:** these are the exact warnings I misdiagnosed
earlier in this project, when I told Sebastian they were stray labels in the root sheet
and he deleted working ones on my advice. They are not stray. KiCad reports them at the
parent path because hierarchical connectivity resolves there, and they are benign until
the parent is wired. Nothing gets deleted.

**On SW_B / COIL_B:** KiCad will use `SW_B` in the netlist. Leave it. Deleting the local
`SW_B` label to force the other name would split the node — U2's VS pin and C16 sit in a
separate wire region joined only by that label, and they would be orphaned.

### Gate turn-off network — derivation now on record

The design sheet §4.3 called for 4.7 Ω + diode across each gate resistor without showing
the arithmetic, and I initially argued the case was weak based on a guessed C_rss of
~60 pF. Checked it against the datasheet instead: **IRF100B201 C_rss = 310 pF,
V_GS(th) = 2.0 V minimum, Q_gd = 45 nC.**

    t_miller = Q_gd / I_g   = 45 nC / 0.4 A        ≈ 112 ns
    dV/dt    = 60 V / 112 ns                       ≈ 0.54 V/ns
    i        = C_rss × dV/dt = 310 pF × 0.54e9     = 167 mA
    V_gs     = i × (R_gate + R_driver_sink)
             = 0.167 × (10 + ~3)  = 2.2 V     ← vs 2.0 V min threshold
             = 0.167 × (4.7 + ~3) = 1.3 V     ← with the network

A worst-case-threshold part starts conducting as originally drawn. §4.3 was right and my
scepticism was wrong; the difference was five times the reverse transfer capacitance.
The lever is the *victim's* gate impedance, not the aggressor's slew rate — turn-on stays
at 10 Ω deliberately, because speeding it up would raise dV/dt and make it worse.

### Two errors caught during the build, both mine

**Approving from a screenshot.** Sebastian showed me the first gate-turn-off branch and
I said it was correct — from the image, immediately after writing a document about why
images are not evidence. It was reversed. He then replicated it four times. As built it
would have been *worse than fitting nothing*: the diode bypassed the 10 Ω on turn-on,
raising dV/dt to 1.25 V/ns and the induced gate voltage to 5.0 V.

**Mirror is not rotation.** The first fix attempt mirrored the diodes instead of rotating
them, and nothing changed electrically. Worth recording why: a diode's two pins both lie
on the library x-axis, so at 90°/270° each pin's sheet-y depends only on its library-x.
Mirror-X negates library-y, which is zero for both pins — it repaints the body and moves
nothing. Only changing the angle to 270 swapped the ends. The picture changed and the
netlist did not, which is a compact illustration of why the file is the thing worth
checking.

### Remaining before layout

- Cosmetic: the BUS DECOUPLING annotation still overlaps wiring. Plot to PDF to confirm.
- Export the netlist to `levpdu/`.
- Netclasses (POWER / GATE / Default) before opening the PCB editor.
- Deferred by decision, not oversight: bulk electrolytics and the bus bleed resistor move
  to the shared BUS sheet; OCP hard-off accepted for rev 0.

---
*Log continues.*

---

## 2026-08-13 (later) — the shunt nearly took the board out, and F8 caught it

`power_channel` is closed. The last hour was spent on a fault that no ERC run would ever
have found, and it is the most instructive thing in this log.

### A 4-terminal footprint under a 2-pin symbol

After switching R11 to the Vishay WSK2512 land pattern, "Update PCB from Schematic"
returned:

    Warning: No net found for component R11 pad 4 (no pin 4 in symbol).
    Warning: No net found for component R11 pad 3 (no pin 3 in symbol).

Read casually that says "two unused pads". It did not. Pulling the pad geometry out of
KiCad's own `.kicad_mod` gave the real numbering:

| Pad | Role | Size | End |
|---|---|---|---|
| 1 | current | 3.3 × 2.03 mm | left |
| 2 | **sense** | 1.4 × 0.76 mm | left |
| 3 | **sense** | 1.4 × 0.76 mm | right |
| 4 | current | 3.3 × 2.03 mm | right |

Current terminals are **1 and 4**; sense terminals are **2 and 3**. That is Vishay's
numbering, not the sequential order anyone would assume. R11 was still a `Device:R` with
pins 1 and 2, so KiCad mapped SW_A to pad 1 (correct, large) and **COIL_A to pad 2 — a
1.4 × 0.76 mm sense terminal.** The full 30 A coil current would have been routed into a
sense pad while the large current pad on the far side sat unconnected. First power-up
failure.

And the Kelvin taps went nowhere, so the board would also have had 2-terminal sensing —
the exact defect the 4-terminal part was bought to fix.

### Fix

`Device:R_Shunt` (4 pins: 1 and 4 current, 2 and 3 sense, each sense tap adjacent to its
own current terminal) matches the footprint numbering exactly. Swapped via Change Symbol
so reference, value and footprint survived, then rewired — and critically, R12 and R13
were moved off the current nodes, which is the step that is easy to skip and would have
silently preserved the original defect:

    SNS_P     R11.2 — R12.1              Kelvin tap, SW_A end   → route as a pair
    SNS_P_F   R12.2 — C19 — U3.8 (IN+)   filtered, at the chip
    SNS_N     R11.3 — R13.1              Kelvin tap, COIL_A end
    SNS_N_F   R13.2 — C19 — U3.1 (IN−)
    SW_A      R11.1 (current)   COIL_A   R11.4 (current)

Sign preserved: SNS_P is the SW_A-side tap feeding IN+, so positive coil current still
reads above 1.65 V and the ±45 A window is the right way round. Had the sense pair been
crossed, the over-current trips would have fired on the wrong polarity — a fault that
would only show up on a real coil.

`R_Shunt` is also 2.54 mm wider than `Device:R`, which left the old wires overshooting the
new pins by 1.27 mm each side. Fixed.

### The lesson

**A footprint's pad numbering is a datasheet fact, not a convention.** The failure lived
entirely in the symbol-to-footprint pin mapping — invisible in the schematic, invisible
to ERC, visible only at the moment the schematic met the board. Which is an argument for
running F8 early, before layout is a sunk cost, rather than treating it as the last step.

Also worth stating plainly: this was introduced by *my* recommendation to move to a
4-terminal shunt. The advice was right; I gave it without checking that the symbol could
carry four pins.

### One more retraction: my own tooling had a bug

The first netlist cross-check disagreed with KiCad on exactly one thing — which end of R8
was pin 1. Cause: my mirror handling applied the flip in library space rather than output
space, which swaps pin numbering on any symbol that is **both rotated and mirrored**. R8
(270°, mirror X) is the only such symbol on the sheet, so it was the single part capable
of exposing it. No electrical consequence — a resistor is symmetric and net membership was
identical — but every rotated-and-mirrored part reasoned about earlier in this project
carried a latent pin-swap risk. Fixed, re-run, exact match.

That is the argument for the cross-check. Two independent methods disagreeing by one pin
number is how you find out one of them is wrong.

### Final state of `power_channel`

- **ERC:** 12 errors, 7 warnings — all traced to `AUX_RAILS`/`IO_PROTECT` not existing yet,
  plus the intentional SW_B/COIL_B naming. The new `isolated_pin_label` on COIL_A is
  positive evidence the Kelvin rewire took: COIL_A now holds exactly one pin inside the
  sheet because R13 correctly left it.
- **Update PCB from Schematic: 0 errors, 0 warnings.** 60 footprints, 39 nets.
- **Netlist cross-check: exact match on all 39 nets, pin for pin**, between KiCad's
  netlister and an independent reconstruction from raw symbol geometry.
- **Netclasses:** 6 classes (Default, HV_POWER, SENSE, GATE, AUX, ANALOG), 15 patterns,
  every named net resolving to exactly one class. `SNS_P`/`SNS_N` are a differential pair
  in the SENSE class — KiCad's `_P`/`_N` convention means the DP router will handle them
  as a coupled pair, which is the layout half of what the INA240 needs to reject 60 V of
  common mode.

Remaining before layout: BOM export, `min_clearance` 0.0 → 0.2, annular ring 0.1 → 0.13,
and copper 0.035 → 0.07 mm (2 oz — the board is not buildable at 1 oz).

---
*Log continues.*

---

## 2026-08-14 — BUS, IO_PROTECT, root wiring. Schematic complete.

The remaining three sheets and the root are done. **84 nets, 156 components, ERC 0 errors
and 1 accepted warning, netlist verified against an independent reconstruction.**

### BUS — power entry

Battery in on J101 (Molex 38969-0002, now approved by the lead), six 470 µF bulk
electrolytics, 22 k bleed, PWR_FLAGs on +60V and GND.

Two things worth recording. The bulk bank is **sized by ripple-current rating, not
capacitance** — ~20 A RMS on the shared bus once the two channels interleave 180°, so the
part count follows whatever ripple rating the chosen capacitor has rather than a target
microfarad number. And the bleed resistor was re-derived after the bank grew: 22 k against
2820 µF is τ = 62 s, so 60 V → under 10 V in ~110 s, not the ~40 s implied when the bank
was two capacitors. 5.1 J stored.

### The fuse is now a harness item, not a board part

Originally drawn as F101 on this sheet. Reversed after pulling the actual mechanical data:
the MIDI HP is a **bolt-down chassis component** — roughly 48 × 36 × 16 mm on M6 studs —
designed to bolt to a bus bar, not to FR4.

On-board it would have cost ~50 × 40 mm plus socket access at the battery entry, put M6
clamp load onto a 1.6 mm board through thermal cycling, and carried 60 A across a bolted
joint instead of a soldered one. In the harness it costs nothing, is what the part is for,
and **also protects the battery cable** — which a board-mounted fuse never could. A chafe
upstream of J101 is invisible to an on-board fuse.

Requirement recorded on the sheet as a text block, because it now lives outside this
board's boundary: **70 A Littelfuse MIDI HP, 70 VDC, 2500 A interrupting, mounted at the
battery.** Most automotive fuses are 32 V and are not acceptable. The note also states
explicitly that nothing fuses J101 locally, so no one reading BUS in isolation can
conclude the board is unprotected.

### IO_PROTECT — board I/O

Four connectors (rails in, 12-way control, two yoke outputs), PWM input buffering, output
conditioning, rail entry protection.

**Buffer choice — 74LVC2G17 at 3.3 V, and the reason is not the obvious one.** The library
had no HCT part, and 74HC7014 at 5 V needs 0.7 × VCC = 3.5 V to register a high, which a
3.3 V MCU cannot produce — that would have silently reintroduced assumption A4. LVC's
inputs accept up to 5.5 V *regardless of VCC* (verified on the SN74LVC2G17 datasheet), so
powered from 3.3 V it takes a 3.3 V or a 5 V MCU with no assumption either way. Output
drives the IR2184's 2.7 V VIH with 0.6 V of margin; the datasheet lists 3.3 V drive as a
supported configuration.

**10 k pulldowns on the four buffer inputs are a safety item.** An unplugged harness leaves
an LVC input floating, which oscillates. Pulled low, both IR2184 inputs sit low, both low-
side FETs turn on, and each coil is shorted through Q2/Q4 — slow decay. The safe state is
the default state whenever nothing is connected.

**RESET is pull-low-only, and this is a firmware constraint invisible from the schematic.**
The 74HC74 runs from +5 V and needs 3.5 V to release CLR. A 3.3 V MCU driving RESET high
push-pull would sit at 3.3 V — ambiguous — and the latch could stay permanently cleared,
losing fault latching entirely. Drive low to clear, then release; the on-board pull-up
provides the high level. Written onto the sheet.

**ISNS output filtering.** 100 Ω + 100 nF, with the capacitor on the *connector* side of
the resistor. First drawn with the cap on the amplifier side, which was wrong twice over:
it hung 100 nF directly on the INA240 output with no isolation resistor (stability), and
it loaded the very node the window comparators watch. On the connector side the resistor
isolates the amplifier and the RC gives a 16 kHz filter on the outgoing copy — while the
comparators tap ISNS upstream on power_channel, so the over-current trip stays fast.

### Rail protection, and a gap it exposed

D201/D202 are series Schottkys on the incoming +12 V and +5 V. Each does two jobs: blocks
reverse polarity, and **isolates the hold-up capacitor** so it cannot back-feed into a
collapsing pod rail — which is the job C201 exists for in the first place.

+3.3 V deliberately gets none. A 0.35 V drop would cost ~10 % of the current-sense
full-scale range, and losing 3.3 V **fails safe**: the buffer outputs go low, the IR2184
inputs go low, the low-side FETs turn on, slow decay.

Working through that rail by rail exposed something. Slow-decay-on-fault needs two things
true at once:

    12 V alive     → drivers can hold the low-side FETs on     C201 covers this
    SD held HIGH   → drivers not shut down                     nothing covered this

SD is driven by U5 pin 6 — the 74HC74's Q̄ — **and that chip runs from +5 V**. If the 5 V
rail dies mid-fault, R19's pulldown drags SD low, the bridge tri-states, and the coil dumps
into the bus: exactly what §3.2 exists to prevent. The board was half-provisioned — 12 V
anticipating a feature the 5 V rail equally depends on. Fixed by giving +5 V the same
treatment: blocking diode plus 220 µF.

Neither is exercised yet — the bus-fault detector §3.2 describes still isn't designed, and
the OCP path remains hard-off by accepted rev-0 decision. But provisioning half of a
mechanism is worse than provisioning none, because it looks finished.

### Root — dual instantiation

CH1 and CH2 both point at power_channel.kicad_sch. Thirteen nets joining IO_PROTECT to the
two channels, drawn as short stubs with matching local labels rather than long wires.
RESET is the only one-to-many, shared by both channels.

### The #PWR duplicate episode

Annotating with "Keep existing" produced 32 "Duplicate items" errors and KiCad refused a
full ERC: *schematic is not fully annotated*. All 253 instance-references were assigned —
the problem was that every `#PWRxx` was identical across CH1 and CH2, because power symbol
references were already set and "keep existing" kept them. Real components renumbered
correctly into the gaps the 100/200 blocking had left (CH2 took C211–C231, R210–R232,
D203–D209, Q201–Q204, U203–U207 with zero collisions).

Fixed by rewriting **only CH2's path references** to #PWR0301–#PWR0332 directly in the
file, after diffing CH1's full 96-reference list before and after and asserting equality
before writing. The obvious alternative — KiCad's "Reset existing annotations" — would have
renumbered all 120-odd real components across the design to fix something cosmetic,
invalidating the review document, this log and the netlist snapshot.

Worth remembering as a hierarchical-design gotcha: **power symbol references are per
instance path, and "keep existing" will not make them unique for you.**

### Verification

- **ERC: 0 errors, 1 warning** — the SW_B/COIL_B naming, reported once because both
  channels share a sheet file.
- **Netlist cross-check: exact match on all 84 nets, pin for pin**, between KiCad's
  netlister and a reconstruction built from raw symbol geometry, rotation matrices and
  hierarchical label resolution across four sheets and two instances.
- That check found one more bug in my own tooling: PWR_FLAG lives in the `power:` library,
  so it was being treated as a net-naming symbol and keyed on its Value — welding +60V,
  +12V, +5V, +3.3V and GND into a single net. A flag is a marker, not a name. Second
  tooling bug the cross-check has caught, after the mirror-transform error on R8.
- **All 37 capacitors now carry a Voltage field.** The bus bank had been covered only by a
  text note, but the note lives on the drawing and the BOM is what people order from.

### Remaining before layout

One custom footprint (Molex 38969-0002, used by J101/J203/J204). J201 and J202 still need
real parts chosen — pick something KiCad already has footprints for and that count goes to
zero. Board Setup values and 2 oz copper are done.

---

## 2026-08-14 (later) — footprints, connectors, and a retraction I should not have needed

The schematic was electrically finished. What stood between it and a board was that a
footprint is a physical claim — this part, these pads, this pitch — and nothing in ERC
checks whether that claim is true. Every error in this phase is silent until a part
arrives and does not fit.

### Connectors: single-row Micro-Fit, chosen to avoid rework

J201 and J202 (the logic-side connectors) were the last parts with no footprint. The
question was not "which connector is best" but "which connector do the symbols already
drawn support without redrawing them", because the symbols are single-row `Conn_01x04` and
`Conn_01x12`.

    J201  Molex Micro-Fit 3.0  43650-0400   1×04  P3.00mm  Horizontal
    J202  Molex Micro-Fit 3.0  43650-1200   1×12  P3.00mm  Horizontal

Micro-Fit 3.0 rather than a header strip because these carry PWM, RESET, ISNS and FAULT
between boards on a moving vehicle: the family latches, is mechanically keyed so it cannot
be seated backwards or in the wrong socket, and is rated well past anything on those pins.
Single-row rather than the more common 2×N because the dual-row variants would have meant
re-drawing both symbols with a different pin order and re-verifying the netlist — real work
in exchange for a slightly smaller footprint on a board that is not space-constrained.
Horizontal so the harness leaves the board edge rather than standing off the face, which
matters once a heatsink extrusion is bolted over the power stage.

**These are board-side parts only.** The mating housings and crimp terminals are harness
items and are not in this project's BOM. They need to be on the harness BOM before anything
is ordered, or the boards arrive with nothing to plug into them.

### The fuse left the board

F101 was deleted from the BUS sheet. The trigger was checking the physical part rather
than the symbol: a MIDI-class bolt-down fuse at this current is roughly 48 × 36 × 16 mm on
M6 studs. That is not a component you place — it is a piece of hardware you mount, and
putting it on the PCB means the board carries the mechanical load of two M6 joints plus
whatever the harness does to them.

Moving it into the harness upstream of J101 is better on the engineering merits and not
just the packaging ones: **a board-mounted fuse does not protect the cable feeding it.** A
harness fuse at the battery end protects the cable and the board. The board keeps its bus
entry connector; the protection moves to where the fault energy actually comes from.

Logged as a deliberate scope move, not a deletion — the fuse still exists in the system,
it is just not this board's part.

### A project footprint library

    ${KIPRJMOD}/lib.pretty    registered in fp-lib-table as `lev_lib`

Registered by project-relative path, not absolute, so the repository is self-contained: a
clone on another machine resolves the library with no configuration. Anything KiCad does
not ship lives here rather than in a user-global library that would not travel with the
project.

### RETRACTION — I told him not to use a correct footprint

The Molex 38969-0002 (bus and coil terminals, J101/J203/J204) is not in KiCad's libraries.
He found a vendor-generated footprint, and I examined it and told him it was wrong:

    pad 1 at (0.000,  0.000)
    pad 2 at (12.700, 13.000)

Two through-holes offset in **both** axes — staggered. Mouser's parametric table for the
part says *Number of Rows: 1*. A single-row connector's pins are collinear. I concluded the
footprint generator had produced garbage and advised against using it.

I was wrong, and the way I was wrong is the same failure as the LM393 episode on 08-13.

He pushed back — the part is genuinely still sold, and a second, independently generated
footprint from a different source showed the same staggered geometry. **Two independent
vendors agreeing should have stopped me immediately.** Instead I kept the conclusion and
looked for reasons the evidence was bad.

Resolved by parsing the manufacturer's own STEP model — the physical solid, not a table
about it. The pins are at:

    (-6.350, -6.502)  and  (+6.350, +6.502)      ΔX = 12.700   ΔZ = 13.004

Staggered, exactly as both footprints drew them, to within 4 µm of the footprint's 13.000.
The footprints were right. My reading of the spec table was wrong: **"Number of Rows"
describes terminal rows in the housing, not hole rows in the PCB.** A single-row connector
can absolutely have staggered PCB pins — the stagger is a retention feature, it stops the
part rocking out under vibration, which is precisely why you would pick this family for a
pod.

The lesson is the same one, restated: *a spec table is a summary written by a person; a
STEP model and a land pattern are the geometry itself.* When a summary and two independent
pieces of geometry disagree, the summary loses. I had this lesson written down already
(08-13, "constraints before evidence") and did not apply it. Writing a rule down is not the
same as having it.

The cost of this one was low — an hour and some doubt — but the failure mode is expensive:
had he taken my advice, he would have hand-drawn a replacement footprint for a part whose
correct footprint he already had, and hand-drawn footprints are exactly where mechanical
errors come from.

### Choosing between the two candidate footprints

Both were correct on pin positions. They differed on copper:

| | first candidate | SamacSys (chosen) |
|---|---|---|
| Pad diameter | 4.4704 mm | **5.940 mm** |
| Drill | 3.96 mm | 3.96 mm |
| Annular ring | 0.25 mm | **0.99 mm** |
| 3D model | none | 38969-0002.stp |

At the same drill, the annular ring is the whole difference, and 0.25 mm is thin for a
terminal that carries the full bus current and takes mechanical load from a ring lug being
torqued down. 0.99 mm gives four times the copper around the barrel to conduct through and
to resist pad lift. The 3D model is a second, independent reason: it is what let this
retraction be settled by geometry instead of argument, and it will do the same job again
during mechanical fit-check against the heatsink.

### Verification

**Update PCB from Schematic (F8): 0 errors, 0 warnings, 156 footprints.** Zero missing.

Both channel instances produced identical footprint sets, which is the check that matters
for a multi-instance sheet — if one instance had picked up a stale assignment, the two
would diverge:

    CH1   D1/D3 SMA · D2 SMC · D4–D7 SOD-123 · R11 WSK2512
    CH2   D208/D209 SMA · D205 SMC · D203/204/206/207 SOD-123 · R219 WSK2512

**The schematic phase is closed.**

### What the board needs before placement can start

Three mechanical inputs, none of which are engineering decisions I can make from here:

1. **Board outline** — dimensions and the envelope it has to live in.
2. **Mounting holes** — positions, diameter, and whether any are electrically bonded.
3. **Heatsink** — the extrusion's part number or profile, and how it mounts, because
   ~1.35 °C/W is a substantial piece of metal and its geometry decides where the row of
   eight TO-220s can physically go. Everything else on the board places around them.
4. **Harness entry edge** — which side the bus and coil cables come in from, which sets
   where J101/J203/J204 go and therefore where the high-current pours run.

Placement order once those exist: outline → the eight TO-220s against the heatsink edge →
local 1 µF ceramics at each bridge → IR2184s within ~15 mm of their FETs → shunt and
INA240 with SNS_P/SNS_N routed as a tight pair → J203/J204 → J101 and the bulk cans →
J201/J202 and the logic.

### Still open, unchanged

- Coil L, k and R remain unmeasured. A1 stays an accepted assumption by the lead's
  decision, not a measurement.
- The bus-fault detector of §3.2 is still undesigned; OCP remains hard-off for rev 0.
- Micro-Fit mating housings and crimp terminals need to be added to the harness BOM.

---

## 2026-08-14 (later still) — mechanical baseline fixed by decision; the 4-yoke question answered

### First: yes, four yokes. This board is half the pod on purpose.

Sebastian asked whether I knew the pod has four yokes, having noticed this board only
drives two. It does, and the two-channel count is a decision from Day 1, not an oversight —
`04_board_partitioning.md` §4 recommends **two identical 2-channel boards**, and §2.1
gives the reason: bus current is set by yoke current × channel count and is independent of
topology.

    4 channels × 30 A/yoke  →  120 A into one board   ≈ 48–73 mm of uninterrupted 2 oz copper
    2 channels × 30 A/yoke  →   60 A into one board   comfortable

120 A is a genuinely hard PCB problem on a board where the connectors and bulk caps
interrupt the pour anyway. Secondary reasons, all still holding: 8 TO-220s bolted to a
common heatsink instead of 16 (§3.1); a layout error costs a small re-spin instead of
taking the pod down (§3.2); one spare covers either position (§3.3); and the two boards are
one layout, so it is one design either way.

Explicitly **not** inherited: the overview document's fault-tolerance argument (a lost
diagonal keeps support balanced). That premise is still unverified — Q16, "is the pod
controllable on two yokes at all", was never answered. The two-board case stands without
it.

**What this does open, though, is the PDU question, and Sebastian's observation is the
right trigger for it.** Two boards means something upstream has to split the pack and fuse
it. `04_board_partitioning.md` §5 is unambiguous about the answer: **buy it, don't build
it.** Designing a 120 A PCB is the hardest problem in the project and a solved commercial
one. Two live cautions carried forward from that section:

- Most marine/automotive distribution blocks are rated **≤48 V DC**. This bus is 60 V.
- Standard ANL and MIDI bolt-down fuses are commonly rated **32 V DC** — invalid here. The
  Victron MEGA-fuse has an **80 V DC** variant. DC interrupting capacity does not
  extrapolate upward from a lower-voltage part; check it, don't assume it.

This also means the harness fuse decided earlier today is per-board, downstream of whatever
distribution block gets bought.

### Mechanical baseline — decided, because nobody upstream is deciding

Asked for board outline, mounting and heatsink, Sebastian's answer was that he gets to
choose and has no constraint driving it. Rather than leave placement blocked on an input
that does not exist, the following is **fixed by decision** and logged as assumptions
A10–A13 in `09_design_sheet_rev0.md` §2, each with its change cost. If a real mechanical
constraint appears later, these are the four things to re-open.

**Outline: 160 × 100 mm (Eurocard).**

Not arbitrary. Eight TO-220s at a realistic ~15 mm pitch need ~120 mm of board edge, and
§4.2 of the design sheet already sized the heatsink at *roughly 150 × 100 mm with 40 mm
fins*. The 160 mm edge and the extrusion are the same dimension — the board is as long as
the thing that cools it. Eurocard is also a standard every fab prices normally, and
standoffs, card guides and enclosures for it exist off the shelf.

**Mounting: 4 × M3, holes 3.2 mm, on a 150 × 90 mm rectangle** (5 mm in from each edge).
Plated, 6.5 mm copper keepout, 7 mm component keepout for a washer and the hex of a
standoff.

**All four holes isolated from every net** — with one deliberate provision: a 0 Ω 1206
jumper footprint between the hole nearest the bus entry and GND, unstuffed by default.

That last part is the only real engineering content in the mechanical set. The yokes float
today; `03_open_questions.md` records the lev team saying the only common point is at the
motor-controller negatives. Bonding this board's ground to chassis through a mounting screw
would create a second, unplanned return path for 60 A of switching current — through the
pod structure. So: isolated by default, bondable by stuffing one part, and no re-spin
either way. A decision that can be reversed with a soldering iron does not need to be
right today.

**Heatsink: extrusion bolted along one 160 mm edge**, TO-220 tabs vertical against the fin
base, M3 through each tab into a tapped hole in the extrusion. Every device gets an
insulating pad — Q1/Q3 tabs sit at +60 V and Q2/Q4 tabs at the switch nodes, so the eight
tabs on this board are at **five different potentials** and none of them may touch the metal.
The 1.5 °C/W silpad is already in the §4.2 budget.

No specific extrusion part number yet. 1.35 °C/W in natural convection is a substantial
piece of metal, and A6 (40 °C ambient) and airflow (Q20) both move it — that is a part to
select against a real datasheet, not to guess at.

**Harness entry: power on the short edges, logic on the far long edge.**

    ┌──────────── heatsink extrusion, 160 mm ────────────┐
    │              Q1–Q4  ·  Q201–Q204                    │
    J101                                          J203/J204
    (bus in)        bulk caps · gate drive        (coils out)
    │        IR2184 · INA240 · LM393 · 74HC74             │
    └──── J201 (4-way rails) · J202 (12-way logic) ───────┘

This falls out of the current path rather than being chosen: bus in → bulk → bridge → shunt
→ coils out is a straight line if the power connectors sit on the two short edges next to
the FET row. Logic goes on the opposite long edge, as far from the switching node and the
commutation loop as a 100 mm board allows.

### Status

Placement is no longer blocked. The remaining genuine unknowns — coil L/k/R, the §3.2 bus
fault detector, Q16 — none of them gate laying this board out.

---

## 2026-08-14 (end of day) — adversarial review of the whole schematic

Full write-up: `16_adversarial_review.md`. Log entry records the method and the lessons.

### Method

Five independent reviewers, each given **only** the extracted netlist and the operating
point — deliberately not the design documents, so nobody could be anchored by my own
rationale. Each was told to break the design rather than confirm it, and each was told that
a false positive costs real trust, so anything they checked and found sound had to be listed
as checked-and-OK rather than quietly dropped. Dimensions: power stage and thermals; gate
drive; current sense and OCP; the logic-level boundary at J202; system failure modes.

Then a sixth pass whose only job was to **refute**. Nine contested claims went to it — ones
where reviewers contradicted each other, or contradicted a part's own marketing copy.

That last pass earned its place. It killed two findings outright and **inverted one
recommended fix**: a reviewer had proposed moving the 74LVC2G17 buffers from +3.3 V to +5 V
as a "free" cure for a thin IR2184 VIH margin. The IR2184's Recommended Operating Conditions
cap the logic inputs at VSS + 4 V, so that change would have taken a compliant 3.3 V drive
and put it *at* the absolute maximum. Had I passed the review through unverified, I would
have handed over a fix that made the board worse — and it would have looked authoritative,
because it came with a datasheet citation attached to the front-page marketing bullet
instead of to the ratings table.

**That is the lesson of the day, and it is the same one as the staggered-pin retraction this
morning, running in the opposite direction.** This morning I trusted a spec-table summary
over two pieces of real geometry. This afternoon a reviewer trusted a marketing bullet over
the ratings table. Both failures are "read the summary, skip the table."

### What came out

Nineteen surviving findings. Seven are pre-layout because they add or change parts. The
headline four:

1. **The fault latch is not set-dominant, and the annotation on the sheet says it is.** A
   74HC74 with `/S` and `/R` both asserted gives Q = H *and* /Q = H — and /Q is the SD net.
   So asserting RESET while a fault is live sets SD **high** and re-enables the bridge into
   the overcurrent. Four of the five reviewers found this independently. It fires on the most
   obvious firmware retry loop there is, and on every power-up while the POR RC holds RESET
   low.
2. **RESET is the only logic line with no level translation.** 74HC74 VIH at a 5 V rail is
   3.5 V; the node sits at 3.33 V. Every PWM line got a Schmitt buffer and this one got a
   100 Ω resistor. Fix is a 74HCT74 — one BOM line.
3. **"PWM low" is not "off".** From the IR2184's own VIL row — *"logic '0' input voltage for
   HO & logic '1' for LO"* — a pulled-down input turns the **low side on**. So the pulldowns
   give a defined state, not a safe one, and a single backed-out PWM pin gives ~30 A of
   uncommanded DC current, below the 45 A trip, with the telemetry reading normal. Worse:
   tracing the netlist, **the MCU has no path to command shutdown at all** — SD is driven
   only by the latch, and RESET only clears it.
4. **The capacitor bank is sized for one modulation scheme and the thermals for another.**
   This one is mine. `09_design_sheet_rev0.md` §4.1 sizes the FET losses under "Antiphase
   (design to this)"; `13_schematic_review_power_channel.md` §3.1 sizes the bank on 15 A RMS
   per channel, which is the **sign-magnitude** number. Locked antiphase in phase is 52 A.
   Six cans give 8–14 A. They only work for sign-magnitude interleaved 180°.

   The two documents were written a day apart, each internally consistent, and the
   contradiction lived in the gap between them. Nothing in ERC, F8 or the netlist
   cross-check can see a fault of that shape — every one of those tools checks the drawing
   against itself.

### Three more corrections to my own record

- `14_power_channel_closeout.md` §3 said a 16 mm can at 470 µF/100 V "is unusual." Backwards:
  Ø16 is the *only* size that value exists in, across Nichicon UPW, Nichicon UVR, Rubycon ZLH
  and Panasonic FR-A. **The Ø18 footprint now on C101–C106 has no part to put in it.**
- The design sheet specified the shunt as "1 mΩ, 4-terminal, ≥2 W." The WSK2512 actually
  fitted is **1.0 W at 70 °C** — half the stated requirement, running at 90 % of rating at
  the design current. The fix that costs nothing elsewhere is 0.5 mΩ + INA240A2 (gain 50):
  same 20 mV/A, same thresholds, same footprint, 45 % of rating.
- Today's earlier entry said the TO-220 tabs sit at six different potentials. Five. Fixed in
  place above.

### The pattern worth keeping

Every one of the four headline findings is a **boundary** failure — between two chips'
logic levels, between the latch and the thing resetting it, between the MCU's model of the
board and the board's actual default state, between two documents written on different days.

None of them is visible in a netlist, because a netlist says what is connected, not what the
connection *means*. ERC is clean, F8 is clean, and the independent netlist reconstruction
matched pin for pin — and all four of these were sitting there the whole time. Worth
remembering the next time a clean toolchain feels like an answer.

### Status

Schematic is **re-opened**, not closed. Seven pre-layout changes, one modulation decision,
and two questions for other people (electronics-bay pressure; whether the slow-decay circuit
gets built for rev 0). Placement waits on those.

---

## 2026-08-14 (evening) — the seven pre-layout fixes, built and verified

Executed `17_rev0_fix_plan.md` blocks 1–6 interactively, one step at a time, with the
netlist re-extracted from raw geometry after every save. Block 7 (the modulation decision)
is a decision, not an edit, and is still open.

### What changed

**Set-dominance and MCU authority — one package.** A **74HCT00** per channel (U6 / U208)
with all four gates used:

    RESET ──[A: tied inputs]──► RESET_N
            [B: RESET_N, FAULT_N]──► RESET_EFF ──► U5.1 (/R)
    U5.6 (/Q) ──[C: with EN]──► SD_N ──[D: tied inputs]──► SD_DRV ──[R26 3k3]──► SD

`RESET_EFF = RESET OR NOT(FAULT_N)` — the latch cannot be cleared while the comparators are
still calling a fault. `SD_DRV = /Q AND EN` — the MCU can now command shutdown, which it
previously could not do at all. R26 against the existing R19 also drops SD from 5 V to
3.76 V, inside the IR2184's 4 V recommended input maximum instead of sitting on its absolute
maximum. HCT rather than HC because EN arrives from a 3.3 V MCU.

**Gate drivers can no longer float.** R24/R25 10 k at the IR2184 IN pins — on the *driver*
side, because the 74LVC2G17's Ioff makes its outputs high-Z when the 3.3 V rail dies, so
R201–R204 hold nothing. Plus D210 (SS34) + C233 (220 µF) on +3.3 V, matching what +12 V and
+5 V already had.

**Sense chain.** R11 1 mΩ → **0.5 mΩ**, U3 → **INA240A2D** (gain 50), R15 24 k → **43 k**,
U4 → **LM2903B**, U5 → **74HCT74**. C25/C26 bypass the two threshold nodes, which had been
sitting at 7.7 kΩ with nothing on them; R27 (1 k) + C27 (4.7 nF) give 4.7 µs of blanking
into the comparators while leaving the telemetry tap unfiltered.

**Bus sheet.** C101–C106 to `CP_Radial_D16.0mm_P7.50mm` with a real part —
**100ZLH470MEFC16X31.5**, Rubycon ZLH, 2.4 A rms. R101 to 2512.

**Connector.** J202 12-way single-row → **2×8 Micro-Fit 3.0, Molex 43045-1600**, repinned so
every PWM line has an adjacent ground and RESET is no longer beside one. FAULT became **OK**:
sourced from SD_DRV instead of Q, through a 10 k / 15 k divider. That inverts the failure
sense — unpowered, unplugged, broken wire and lost +5 V now all read *not healthy*, where
before every one of them read healthy. The same divider removes the 9–19 mA that was being
injected into the MCU's clamp diode through the old 100 Ω.

### Verification

- **ERC: 0 errors.** Two warnings, both the intentional dual-naming kind (SW_B/COIL_B, and
  now SD_DRV/OK).
- **F8: 0 errors, 0 warnings, 181 footprints.** Schematic and PCB agree on 181 parts with no
  orphans in either direction.
- **Netlist cross-check: exact match on all 100 nets, 494 pads, pin for pin**, between
  KiCad's own sync and a reconstruction built from raw symbol geometry.
- **No annotation run was needed** — everything was already numbered, and this time KiCad
  assigned 40 unique `#PWR` references per channel with zero overlap. The 08-13 problem did
  not recur.

### Four things that went wrong, and what they teach

**1. KiCad split a multi-unit package across five reference designators.** In the CH2
instance path, U6's five units came out as U209, U211, U213, U215, U210 — five separate
SOIC-14 chips as far as the board was concerned. CH1's path was fine. Same root cause as the
`#PWR` duplicates: **per-instance annotation on a multi-instance sheet is not automatic, and
"keep existing" will preserve whatever is already broken.** Fixed by patching both the
reference *and* the `unit` field in each path entry — the references alone were not enough,
because KiCad had also written `unit 1` five times.

**2. A file patch was silently reverted by a save.** I renamed a reference while KiCad had
the file open; his next save wrote the in-memory copy back over it. An earlier patch survived
only because the editor was closed at the time. **Rule adopted: no file surgery while the
editor is open**, and reference tidying is batched to the end rather than done per-step.

**3. My arithmetic was wrong in the review document.** I wrote that 0.5 mΩ with an INA240A2
keeps 20 mV/A and leaves the threshold divider alone. It does not — 0.5 mΩ × 50 = **25 mV/A**,
and holding 20 mV/A would need a 0.4 mΩ shunt, which the WSK2512 does not offer. The real fix
needs R15 to move 24 k → 43 k to keep the trip at 45 A. Caught while writing the step-by-step
plan, corrected in `16_adversarial_review.md` §7. Worth noting *why* it was caught: writing
out the executable steps forced the number to be used rather than asserted.

**4. I quoted a mating half instead of a board half.** I gave Molex **43025**-1600 for J202;
that is the wire-side receptacle housing. The board part is **43045**-1600, and the KiCad
footprint name said so. Third connector-related error of the project, and the second time a
library or vendor artifact caught me before it cost anything.

### One place the tooling was wrong and the schematic was right

The cross-check flagged J202's five ground pins as an island. They had been given plain text
labels `GND` rather than `power:GND` symbols, and my extractor scopes local labels to their
sheet. KiCad merged them into the global ground — the PCB net is `"GND"` with no sheet prefix,
so **the board was correct and my tool was wrong.**

Changed the schematic anyway, to power symbols: the other twelve grounds on that sheet use
them, and depending on a label-scoping subtlety to make a ground connection is not something
that should be load-bearing. After the change, 100 of 100 nets match.

Third tooling bug the cross-check has surfaced, after the mirror transform on R8 and the
PWR_FLAG welding. Every one of them was found by disagreement rather than by inspection,
which is the argument for keeping two independent views of the same file.

### Still open

- **A14, the modulation commitment** — sign-magnitude interleaved 180° vs locked antiphase.
  Everything about the capacitor bank depends on it, and §4.1 of the design sheet currently
  sizes the FETs under the *other* answer. Not an edit; a decision that has to be written
  down.
- Findings 13–16 and 18–19 from the review, deferred by plan.
- Commit, then placement.

---

## 2026-08-14 (night) — delta review, and four defects of my own making

Ran a second adversarial review, scoped to the ~25 parts changed today rather than the whole
board. It found five problems. **Four of the five were caused by this morning's fixes.**

That number is the point of the entry. At the moment those four defects were introduced, ERC
was clean, F8 was clean, and an independent netlist reconstruction matched pin for pin. Every
signal the toolchain can produce said the board was fine.

| | Defect | Whose |
|---|---|---|
| D1 | Board powers up **latched off** — the threshold bypass caps ramp at τ = 841 µs, the POR released at 511 µs, and the latch captured a fault that never existed | mine |
| D2 | Moving VTH_HI to 2.776 V put **both** comparator inputs over the LM2903B's common-mode ceiling at the decision point | mine |
| D3 | The +3.3 V blocking diode moved the trip point from 45.0 A to **39.6 A** and pushed the INA240 under its minimum supply | mine |
| D4 | The /SD divider landed at **2.75 V against a 2.70 V threshold** | mine |
| D5 | RESET's 1 ms edge violates the 74HCT00's input transition-rate limit by 2000× | pre-existing, worsened by mine |

Fixes: C22/C224 → 1 µF · U4 to +12 V · D210 deleted · R26/R19 → 1 k/3.3 k · U6 → 74HCT132.
Re-verified: ERC 0 errors, F8 0/0 at 180 footprints, cross-check **exact on 99 nets, 492
pads**.

### The one I got wrong twice

I told him the trip point was ratiometric — that using the same 3.3 V rail for the INA240's
reference and the threshold divider made rail error cancel. It doesn't. Working it out
properly:

    I_trip = (VTH_HI − V_rail/2) / (G·R_shunt) = 13.65 × V_rail

The trip current is **linear in the rail**, not immune to it. What ratiometric buys you is
that the *MCU's* reading is rail-independent when the ADC shares the reference — a different
and much narrower claim. So the 0.4 V I added with a blocking diode cost 12 % of the trip
threshold.

I asserted that twice in writing before doing the algebra. The check that would have caught
it is trivial and I skipped it because "ratiometric" is a word that sounds like it settles
the question.

### The one where my premise was inverted and the conclusion survived anyway

I flagged the LM2903B common-mode range as a suspected problem, reasoning that both
comparator inputs must sit inside it. The datasheet says the opposite — only *one* input has
to be in range. So the stated premise was wrong.

The finding survived for a different reason: **at the decision point both inputs are at
VTH_HI by definition**, so when the threshold itself exceeds the ceiling, the "one valid
input" allowance does not help. Right answer, wrong reasoning, and I would not have found the
right reasoning without the reviewer correcting the premise first.

Worth recording because the failure mode is subtle: a correct conclusion reached by a wrong
argument is not a verified finding, and it would have been very easy to accept the reviewer's
"REFUTED" and drop a real defect.

### Three symbol/value mismatches now exist

The library lacks LM2903B, 74HCT132 and a Ø16 470 µF/100 V footprint, so the schematic uses
near-equivalents with the true part in the Value and MPN fields. One of these is dangerous if
ignored: fitting an actual **74LS132** would put −0.4 mA through the 10 kΩ EN pulldown, which
cannot hold it, so **EN would float high and the whole MCU interlock would be decorative**.

Collected in `19_bom_caveats.md` so there is one place that says "the symbol name is not the
part number, and here is what happens if you order the symbol."

### Where this leaves the schematic

Closed again, with more evidence behind it than this morning. Two review passes, the second
of which found that the first pass's own fixes were the largest source of new defects. The
process that keeps working is not "review carefully once" — it is **review after every
substantive change, and check the reviewer**.

Open: findings 13–16 and 18–19 from the main review, the §4.1 thermal re-derivation under
unipolar PWM, and coil L/k/R still unmeasured. None block placement.

---

## 2026-08-14 (late) — third review, and the interleave error

Ran a third adversarial pass, this time over the whole design rather than the delta, on the
argument that A14 changed the operating point everything else had been analysed against.
Fourteen findings. The largest was in A14 itself, written six hours earlier.

**The 180° interleave cancels nothing.** Under unipolar PWM the bus draws current only while
Q1 and Q4 are both on, which happens **twice per carrier period** — so the bus-ripple
fundamental sits at 2·f_sw and a 180° carrier shift is a full cycle of it. Verified
numerically:

    D = 0.75    in phase 30.0 A   |   180 deg 30.0 A   |   90 deg 0.1 A
    bank capability 14.1 A

Under locked antiphase the fundamental *is* at f_sw and 180° genuinely cancels. I carried the
requirement across when I changed the modulation scheme and never re-derived it. Left in, the
bank would have run at 2.1× its ripple rating.

Corrected to **90°** in A14, both title blocks, the firmware interface document, and the
on-sheet annotation text. Historical references in this log are left as written.

**Also actioned:** U5 pin 2 (D) moved from GND to +5 V. With D low, a glitch on the CLK trace
clocks a zero in and releases SD out of a latched fault. With D high the same glitch commands
shutdown. One wire, and it changes the failure direction of the whole protection latch.

**Three findings were refuted as artifacts of the review packet, not the schematic** — CH2
"missing" the parts added earlier, U5's three unused outputs "shorted together", and an
IR2184 pin transposition. All three came from errors in how I wrote the packet, and all three
were checked against the raw netlist before being dismissed. Worth noting that a reviewer
finding a contradiction in the *description* is still useful output, and that a review is only
as good as the artifact it is given.

### The convergence problem, stated plainly

Findings by round: **19 → 5 → 14**. Roughly 40 % of the third round traces to changes made in
the first two. The single worst finding exists because I committed a modulation change without
re-deriving what depended on it — and the switching-loss claim in the same paragraph was wrong
for the same reason.

That is not a review-quality problem, it is a sequencing problem. Point-fixing a design whose
foundational input is still unmeasured produces defects faster than review removes them.

**Stopping schematic work here.** The next action is to measure the coil — L, R and k — and
then re-derive bus ripple, per-device loss, heatsink, bootstrap refresh and OCP timing **in
one pass, together**, because those are the quantities that keep breaking each other. Then one
consolidated change set, reviewed once.

Everything in three review documents is a function of numbers nobody has measured.

---

## 2026-08-21 — Layout phase closed to placement; handoff to a second machine

Full record in **`docs/20_layout_phase.md`**. Summary of what happened and what it cost.

**Placement is complete.** 160 × 140 mm, 184 footprints, zero courtyard overlaps, DRC clean
except unconnected. Routing has not started and the **2-layer vs 4-layer decision is still
open** — that is the next thing that has to be settled, and it should be settled before a
single track is drawn.

**The board grew because I measured the wrong thing.** The Ø16 bulk cans did not fit between
the coil connectors, and I had declared the placement feasible using *pad extents* instead of
*courtyards*. The Molex 38969-0002 courtyard is 26.6 × 29.9 mm — far larger than the region
its pads occupy — so on pad extents J203 and J204 read as clear when they were not. Sebastian
caught it from the canvas before I did. The checker was rewritten to read `F.CrtYd`, including
`fp_circle` for radial electrolytics, and that path now produces every clearance number in the
project. Board went 160 × 100 → 160 × 140.

**One structural defect found and analysed.** CH2 had been built as an exact +65 mm translation
of CH1. That is wrong here, because the coil connectors are mirrored — J203 left of CH1, J204
right of CH2 — so CH2's leg A ends up furthest from its own shunt and its SW_A node, 0–60 V at
~0.5 V/ns, has to cross leg B's high-current territory. The fix is to swap the two legs inside
CH2 so it becomes a true mirror rather than a translation. `SW_A 55.6 → 25.8 mm`, at a cost of
`COIL_B2 97.0 → 105.8 mm`. **Analysed and verified, not yet applied.**

**A retraction, in the same session as the claim.** I reported in chat that the swap makes the
two legs "trade" commutation-loop values, 17.7 ↔ 16.7 mm. That was a misreading of my own
output. The loops are **unchanged** — the bridge ceramics move with their blocks and land on
each other's coordinates, so each leg finds a ceramic at exactly the same distance as before.
Corrected in `20_layout_phase.md` §20.4. Separately, the loop figures quoted earlier in chat
(12.9 / 18.7 mm and similar) came from a different metric definition and are not comparable to
the ones now in the document; §20.3 states the definition explicitly so this cannot recur.

**The analysis is now a tool, not a transcript.** Everything above is reproducible by running
`python3 tools/lay.py` from the project root: courtyard overlaps, switching-node spans,
commutation loops, mounting-hole and outline clearances, heatsink-shadow intrusions, plus two
checks specific to the pending edit — a leg-membership audit confirming every leg-local net is
fully contained in one moving block, and a selection-window check confirming the two rubber-band
windows catch exactly the intended 21 footprints each. It also simulates the swap, so the
before/after numbers can be confirmed rather than trusted.

This matters more than it sounds. The script had been living in `/tmp` on one workstation.
Every clearance and loop number in three documents traced back to it, and none of them could
have been re-derived once that machine was gone. It is now in the repository.

**Handoff.** Work is moving to a second computer. `HANDOFF.md` at the repository root carries
the state of the design, the three remaining steps of the leg swap with exact coordinates, the
verification command, and the transfer options — the repository has no git remote, which is
worth fixing now that two machines are in play.

**Unchanged from the schematic close-out:** the coil is still unmeasured. Placement is
structurally sound and resting on numbers nobody has taken yet, which is exactly where the
schematic was when it was closed. §4.1's thermal figures are still derived under locked
antiphase and still need redoing under unipolar.

---

## 2026-08-24 — CH2 leg swap applied; stackup bug; four layers chosen

**The CH2 leg A/B swap is applied and verified.** Leg B −30 mm X, leg A +30 mm X, 42 footprints
including the bridge ceramics, Y and rotation unchanged on every part.

```
/CH2/SW_A       55.6 -> 25.8 mm      the fix
/CH2/COIL_B2    97.0 -> 105.8 mm     the accepted cost
courtyard overlaps                   0
commutation loops    CH2 A 17.7 mm, CH2 B 16.7 mm    unchanged
FET thermal order    CH1 C-H-C-H     CH2 C-H-C-H     preserved
all 42 coordinates exact against the target table
```

**How it went is worth recording.** Three consecutive KiCad "Move Exactly" dialogs landed on
offsets we did not ask for — −32.08, then −33.0, then +29.5, each time as a perfectly rigid
block. The blocks were internally correct every time; only the translation was wrong. Rather
than roll the dice a fourth time, KiCad was closed and the 42 coordinates were patched directly
into the board file.

**Two near-misses in that patch, both caught before writing:**

The first version of the patch script read the file in Python text mode. The board is CRLF —
59,557 line endings — and writing it back would have converted the entire file to LF: a
59,557-line diff for a 42-number change. Caught by comparing the in-memory length against the
on-disk byte count. The applied version is binary-safe and the CRLF count is byte-identical
before and after.

The second was in the stackup fix below, and is recorded there.

---

**The stackup carried 0.007 mm copper.** Ten times too thin, against a documented intent of
0.07 mm (2 oz). Nothing already done depended on it — KiCad does not compute ampacity — but it
propagates into fab outputs, and at 0.007 mm the coil pours would have dissipated ten times the
intended power. Fixed; board total 1.474 → 1.600 mm.

The first attempt at that fix also moved the core to 1.46 mm, which would have made the total
1.62 mm. It was caught in the script's own printed output and reverted immediately. Cheap
lesson: have the script print the number it *computed*, not just the number it wrote.

---

**Four layers, 1 oz inner.** Full reasoning in `docs/21_stackup_and_layers.md`.

The copper-loss argument did **not** decide it. The placed pours are 10.7 mm, which is exactly
the IPC-2221 width for 30 A at ΔT = 20 °C — already correct — and an inner layer saves only
3.1 W of the 9.30 W in the coil paths, on a ~54 W board.

What decided it, in order: choosing four now is free while choosing two and being wrong means a
reroute, since the placement is identical either way. A standard 1.6 mm 4-layer puts the ground
plane 0.2 mm under the FET row instead of 1.44 mm away. The current-sense chain — 0.5 mΩ at
25 mV/A, ×50, with a ±45 A trip standing between a fault and four dead FETs — deserves a
continuous plane beneath it. And with 158 SMD footprints against just 72 through-holes, the
inner plane here is nearly solid.

The case against is recorded in §21.3 rather than omitted: two layers might well work, and on a
volume cost-driven build the 2-layer attempt should be made first. This is a prototype resting
on an unmeasured coil, and margin gets bought where it is cheap.

**Two constraints fell out of the numbers**, both in §21.5. The `HV_POWER` net class has a 3.0 mm
track width covering `+60V`, `GND`, `*SW_*` and `*COIL_*` — routing a 30 A net as a 3.0 mm track
gives a ~164 °C rise, so these nets must be zones, never tracks. And an inner layer only helps
if current can reach it: **20 vias per 30 A layer transition** at 0.6 mm drill.

**Still unmeasured: the coil.** Unchanged since the schematic close-out, and still the thing
every thermal number depends on.

---

## 2026-08-24 (cont.) — Board Setup for four layers; net classes; leg-A ceramics

**Board Setup is reconfigured.** Physical Stackup now carries four copper layers, verified
from the board file rather than the dialog: F.Mask 0.01 / F.Cu 0.07 / prepreg 0.2 / In1.Cu
0.035 / core 0.97 / In2.Cu 0.035 / prepreg 0.2 / B.Cu 0.07 / B.Mask 0.01, summing to exactly
1.600 mm. In1.Cu and In2.Cu are typed `power`.

The only number that carries design weight is the **0.2 mm F.Cu→In1.Cu prepreg**. Loop
inductance over a return plane goes as μ₀·h/w, so for a 10 mm length of the 10.7 mm pour:
1.69 nH at h = 1.44 mm (two layers) against 0.235 nH at h = 0.2 mm — about 1.5 V less overshoot
per 10 mm of run at 30 A in ~30 ns. Everything else in the stackup is bookkeeping to reach
1.600 mm, and 0.97 mm is not a stocked core; it is the residue. Logged as **A15**.

**The fab question is half answered.** JLCPCB lists 2 oz outer as a standard FR4 option and
1 oz inner as an available multilayer option — but inner copper **defaults to 0.5 oz**. If 1 oz
inner is not ordered explicitly, the In2.Cu parallel-copper saving falls from 9.30 → 6.20 W to
9.30 → 7.44 W. That is an ordering checkbox, not a design change, and it is easy to lose.

**The `HV_POWER` trap is closed.** The 3.0 mm class width was re-derived independently before
being changed: IPC-2221 external, `I = k·ΔT^0.44·A^0.725`, k = 0.048 gives 1166 mil² (10.6 mm at
2 oz) for 30 A at ΔT = 20 °C, and 3.0 mm reversed out at **160 °C** — matching §21.5’s 164 °C
closely enough to confirm it. Resolved against all 99 nets, the class also contained `GND`
(119 pads) and the four bootstrap nets, so every logic ground stub defaulted to 3.0 mm. Split
into `HV_POWER` (7 nets, 62 pads), `HV_BOOT` (4 nets, 12 pads) and `PWR_GND` (1 net, 119 pads);
`*VBATT*` matched nothing and was deleted. Logged as **A16**.

Clearance was left at 0.3 mm on evidence rather than raised on instinct. IPC-2221B Table 6-1 at
51–100 V wants 0.13 mm coated and 0.6 mm uncoated; under mask 0.3 mm is 2.3×, and the uncoated
case is set by pad geometry, not by a net class. Measured across 89 HV pads with true rotated
pad outlines, the tightest 60 V pair is **0.635 mm** — the TO-220 lead pitch — which passes the
uncoated requirement by 6 % and which no net class can change. Worth remembering before anyone
specifies conformal coating or an altitude rating.

**Two DRC rules now enforce what documents used to.** A `track_width (min 10.7mm)` constraint on
`HV_POWER` makes an under-width 30 A track an error, and `disallow track` on In1.Cu makes
§21.4’s "no routing, ever" a machine check. This is the `lay.py` lesson applied again: a rule
that lives in a document is only as good as your memory of it.

A note on testing them. The first attempt drew a track on `+60V` and got no violation — which
looked like a broken rule and was not. The netclass width had just been set to 10.7 mm, the
router used it, and a 10.7 mm track legitimately passes. The trap is that **"no violation" is
equally consistent with "the rule works" and "the condition never matches"**, so a rule is not
proven until something that should fail does.

**Leg-A bridge ceramics rotated 180°.** Found at the start of routing; full record in
`20_layout_phase.md` §20.8. The C-H-C-H thermal order forces leg A to be low-then-high and leg B
high-then-low, so leg A wants +60 V on its right while every ceramic sat at 0° with +60 V on the
left. Ten parts rotated, positions untouched: **CH1 A and CH2 A loops 17.72 → 12.89 mm**, leg B
unchanged, overlaps still 0. The board’s worst-case commutation loop is now leg B at 16.81 mm.

Applied by `tools/rot_ceramics.py`, which refuses to run against a locked board file, and which
recomputes the loops and the 184-footprint courtyard check from its own patched buffer before
writing anything.

**Routing still has not started.** §21.7 step 1 needs amending first: the ceramic +60V and GND
pads alternate along the row at 3.1 mm pitch, so two F.Cu regions would have to interdigitate,
and in leg A they would cross outright. The intended answer is the one four layers was bought
for — +60 V on F.Cu, GND returning through the In1.Cu plane directly beneath it. Not yet
designed.

**Still unmeasured: the coil.** Unchanged.

---

## 2026-08-24 (cont.) — In1.Cu plane; a warning chased to ground

**The In1.Cu ground plane is in.** One zone, whole board (100,50)–(260,190), net GND, pad
connection **Solid**, filled edge landing at 100.5 / 259.4995 where the 0.5 mm edge-clearance
rule put it. Solid rather than thermal relief is not a preference: the low-side FET sources are
where the whole 30 A leg current enters the plane, IPC-2221 internal wants **55.9 mm** of 1 oz
copper for 30 A at ΔT = 20 °C, and four 0.5 mm spokes provide 2 mm. Twenty-eight times short.
The cost is that those TO-220 source pins will be hard to hand-solder.

**DRC unconnected fell 393 → 374, which is exactly right.** 492 pads across 99 nets gives 393
ratsnest connections with nothing routed. An inner plane can only reach through-hole pads, and
`GND` has exactly 20 of those — four FET sources, the bulk cans, and six connector pins — so
they merge into one group and the count drops by 19. The other **99 SMD GND pads are
electrically untouched by the plane** until each has a via. Predicted before the number was
read, and KiCad’s own report agreed.

**Ten `lib_footprint_mismatch` warnings, chased to the end.** Full record in
`20_layout_phase.md` §20.8. The flagged list was exactly the ten rotated ceramics, which looked
like proof the file patch had done something the GUI would not. Redoing the rotation in the GUI
left the footprint blocks **byte-identical** and the warnings in place. Geometry was then
compared against this machine’s own library file as parsed S-expressions: pads, courtyard,
fab rect, silk lines, attr and model path all identical. Cosmetic, cause not isolated, severity
set to Ignore with the reason recorded.

Two claims were made and withdrawn along the way — "it must be the library" and "KiCad rewrote
my patch, so the tool was unfaithful". Both are in §20.8. The method that settled it was the one
that should have been used first: round-trip through the application and diff.

---

## 2026-08-24 (cont.) — the placement review, and one structural finding

Placement had been signed off. It was signed off against six geometric checks, all of which
passed while two current-sense amplifiers sat 38 and 62 mm from their only bypass capacitor. The
prompt to look was a remark from outside the project about I/O filter capacitors. That is not a
process, so the first move was to make it one: `lay.py` gained eight checks covering decoupling
distance, filter placement, gate path, bootstrap, Kelvin matching, high-to-low-voltage approach,
silkscreen collisions and test-point presence. Thresholds are named constants with the reasoning
written above them.

It reported **7 FAIL and 16 warn** on a board whose documentation said placement was complete.

Then the eight functional blocks were walked one at a time rather than re-placing anything.
Full record in `20_layout_phase.md` §20.9. Sixteen parts moved across two batches, both by
self-checking tools, and the checks now read **1 FAIL and 10 warn** — the failure being the
absence of test points, which needs schematic work rather than a move.

**The finding that matters is not a part position.** §21.4 assigned the four 30 A coil pours to
F.Cu. Mapping every clear vertical channel on that layer gives 5.80 mm below the bridge, 8.30 mm
through the logic blocks, 2.43 mm below them, and **no continuous channel of any width** from
the bridge to the coil connectors. A 10.7 mm pour has nowhere to go, and necking one to the
widest 5.1 mm available puts a 68 °C rise at 30 A beside the sense amplifier.

B.Cu is obstructed only by 72 through-hole pads and offers the full board width. The pours move
there, paralleled onto F.Cu where a channel exists. §21.4 and §21.7 are amended.

This would have surfaced about a third of the way into routing, after the gate loops and sense
pairs were committed. Every check in this project measured distances between parts; this is
about the space between them, which nothing looked at.

**A pattern named.** Four separate findings across the review were one mistake: a block mirrored
for CH2 where a single part kept CH1's geometry. The bridge ceramics, `C211`, `R238`, and the
CH2 leg order that started all of this.

**Two register corrections.** A11's hole pattern was 150 × 90 mm and the board has 150 × 130;
the entry dated from before the board grew. A17 added for the shared bus section, which carries
both channels at 60 A and needs 28.0 mm against the 10.7 mm everything else was sized for, and
which is why In2.Cu cannot be used for signal routing.

**Two smaller corrections.** §21.3's "224 mV below the LM2903B's common-mode ceiling" is the
INA240's output headroom, not the comparator's input range; the comparator runs from 12 V. And
the IR2184 link in `01_reference_library.md` resolves to an IR21844S file, which is a different
part.

**Still unmeasured: the coil.** Unchanged.

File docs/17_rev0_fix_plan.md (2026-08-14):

# Rev 0 fix plan — exact steps

> **STATUS: blocks 1–6 executed 2026-08-14. This document is a historical record, not live
> guidance.** Two things in it were later corrected: Block 7 recommends sign-magnitude
> (superseded by unipolar 3-level, A14) with a **180°** interleave (corrected to **90°**).
> Current guidance is A14 in `09_design_sheet_rev0.md`.

Companion to `16_adversarial_review.md`. Work through the blocks in order. Save and run ERC
after each block; do not batch them. Every block is independent, so you can stop after any
one of them and still have a coherent schematic.

Total: **8 new part types, ~19 new components per board, ~3 hours.**

Nothing here redraws existing circuitry. Every change is an insertion, a value edit, or a
footprint edit.

---

## Before you start

1. Close KiCad, commit what you have now, reopen. You want a clean point to roll back to.
2. Order these so they arrive before you need them (all SOIC-14 / 0805 / standard):

| Ref | Part | Qty/board | Why |
|---|---|---|---|
| U6, U208 | **74HCT00** quad 2-input NAND, SOIC-14 | 2 | set-dominance + MCU enable |
| U5, U205 | **74HCT74** (replaces 74HC74) | 2 | RESET at 3.3 V |
| U4, U204 | **LM2903BDR** (replaces LM393DR) | 2 | temperature grade |
| U3, U203 | **INA240A2D** (replaces INA240A1D) | 2 | shunt derating |
| R11, R219 | **WSK2512L5000FEA** 0.5 mΩ 1 % (replaces 1 mΩ) | 2 | shunt derating |
| C101–C106 | **Rubycon ZLH 470 µF 100 V, Ø16 × 31.5** | 6 | Ø18 does not exist; 2.4 A ripple |
| D210 | **SS34** (same as D201/D202) | 1 | +3.3 V hold-up |
| J202 | **Molex 43025-1600**, 2×8 Micro-Fit 3.0 | 1 | 2 more pins + repin |

---

## Block 1 — the fault latch and the MCU enable · ~45 min · 1 IC + 4 passives

**Sheet: `power_channel.kicad_sch`.** This is the important one. It fixes findings 1, 3 and
10 with a single package.

### What you are building

```
   RESET ──┬──────────────► [U6A]  1,2 → 3    RESET_N
           │                       (both inputs tied = inverter)
           │
  FAULT_N ─┼───────────────► [U6B]  4 = RESET_N
           │                        5 = FAULT_N
           │                        6 → RESET_EFF ──► U5 pin 1 (/R)
           │
           │            U5 pin 6 (/Q) ──► [U6C]  9  = /Q
      EN ──┴─────────────────────────────►        10 = EN
                                                   8 → SD_N
                                          [U6D] 12,13 = SD_N (tied)
                                                  11 → SD_DRV
                                    SD_DRV ──[R26 3k3]──► SD net
```

`RESET_EFF = RESET OR NOT(FAULT_N)` — so the latch **cannot be cleared while a fault is
live**, which is finding 1.
`SD_DRV = /Q AND EN` — so the MCU can force shutdown, which is finding 3(c).

### Steps

1. Place **U6 = 74HCT00** (`74xx:74HCT00`, footprint `Package_SO:SOIC-14_3.9x8.7mm_P1.27mm`).
   Place it near U5.
2. Power it: pin 14 → `+5V`, pin 7 → `GND`. Add **C24 = 100 nF 0805 25 V** across them,
   right at the pin.
3. **Gate A (inverter).** Wire pin 1 and pin 2 together and label that node `RESET`
   (the existing hierarchical label already carries RESET onto this sheet — just attach).
   Label pin 3 `RESET_N`.
4. **Gate B.** Pin 4 → `RESET_N`. Pin 5 → `FAULT_N`. Pin 6 → new label `RESET_EFF`.
5. **Rewire U5 pin 1.** It currently sits on `RESET`. Delete that connection and connect it
   to `RESET_EFF` instead. *This is the only existing wire you delete in this whole plan.*
6. **Gate C.** Pin 9 → `SD_Q` (a new label on U5 pin 6 — see step 8). Pin 10 → `EN`.
   Pin 8 → new label `SD_N`.
7. **Gate D.** Wire pins 12 and 13 together → `SD_N`. Pin 11 → new label `SD_DRV`.
8. **Break the old SD net.** U5 pin 6 currently connects straight to the `SD` net. Detach it
   and label U5 pin 6 as `SD_Q` instead. The `SD` net now has: R19 (10 k to GND), U1 pin 2,
   U2 pin 2 — and gets its drive from step 9.
9. Place **R26 = 3.3 k 0805** between `SD_DRV` and `SD`. With R19 = 10 k to GND this divides
   5 V down to **3.76 V**, which is inside the IR2184's 4 V recommended input maximum and
   1.06 V above its 2.7 V threshold. That is finding 10.
10. Add a hierarchical label **`EN`**, type **input**, and attach it to the `EN` node.

### Check before moving on
- U5 pin 1 goes to U6 pin 6, **not** to RESET.
- U5 pin 6 goes to U6 pin 9 only.
- The SD net has exactly four things on it: R19, R26, U1.2, U2.2.
- U5 pin 5 (Q) is now unconnected. That is intentional — Block 4 takes the status readback
  from SD_DRV instead, because that also reads back the enable path.

---

## Block 2 — stop the gate drivers floating · ~20 min · 4 passives

Finding 4. Two parts on each sheet.

**On `power_channel.kicad_sch`:**

1. **R24 = 10 k 0805** from the `PWM_A` net to `GND`, placed at U1 pin 1.
2. **R25 = 10 k 0805** from the `PWM_B` net to `GND`, placed at U2 pin 1.

These have to be on *this* sheet, at the driver. R201–R204 on IO_PROTECT are on the far side
of the buffer and do nothing when the buffer loses its 3.3 V supply.

**On `io_protect.kicad_sch`:**

3. Break `J201` pin 3 off the `+3.3V` net. Label J201 pin 3 `+3V3_IN`.
4. **D210 = SS34** (`Diode_SMD:D_SMA_Handsoldering`), anode on `+3V3_IN`, cathode on `+3.3V`.
   Same orientation as D201 and D202 — copy one of them.
5. **C232 = 220 µF 25 V** (`Capacitor_THT:CP_Radial_D8.0mm_P3.50mm`), + on `+3.3V`, − on
   `GND`. Same part as C201/C202.

Now all three rails have identical blocking-diode-plus-hold-up treatment.

---

## Block 3 — the sense chain · ~30 min · 4 passives, 4 value changes

Findings 7, 11, 12, and the RESET level (finding 2).

**Value and part swaps** — these are property edits, no rewiring:

| Ref | From | To | Why |
|---|---|---|---|
| R11 | `1m` | **`0.5m`** · MPN `WSK2512L5000FEA` | 0.90 W → 0.45 W |
| U3 | `INA240A1D` | **`INA240A2D`** | gain 20 → 50, restores the trip point |
| R15 | `24k` | **`43k`** 1 % | see the arithmetic below |
| U4 | `LM393` · `LM393DR` | **`LM2903B`** · `LM2903BDR` | 0–70 °C → −40/+125 °C |
| U5 | `74HC74` | **`74HCT74`** | belt and braces on the RESET level |

**The threshold arithmetic, so you can check me.** 0.5 mΩ × gain 50 = **25 mV/A**, not the
20 mV/A you have now. For the trip to stay at ±45 A you need ±1.125 V around the 1.65 V
mid-point, i.e. VTH_HI = 2.775 V and VTH_LO = 0.525 V. With R14 = R16 = 10 k and R15 = 43 k,
total 63 k:

    VTH_LO = 3.3 × 10/63 = 0.524 V   →  (1.65 − 0.524)/0.025 = 45.05 A
    VTH_HI = 3.3 × 53/63 = 2.776 V   →  (2.776 − 1.65)/0.025 = 45.05 A

Full scale becomes ±66 A instead of ±82 A — a better match to the 60 A device ceiling, and
inside the INA240's real guaranteed output swing.

**New parts** — the comparator blanking, finding 11:

6. **C25 = 100 nF 0805** from `VTH_HI` to `GND`, at U4 pin 3.
7. **C26 = 100 nF 0805** from `VTH_LO` to `GND`, at U4 pin 6.
   (Those two nodes are 7.7 kΩ Thévenin with nothing on them today, next to a 60 V bridge.)
8. **R27 = 1 k 0805** in series between U3 pin 5 and the comparator inputs. Concretely:
   U3 pin 5 keeps the `ISNS` label — that is what goes out to the connector, unfiltered.
   R27 goes from `ISNS` to a new label `ISNS_F`. Move U4 pin 2 and U4 pin 5 onto `ISNS_F`.
9. **C27 = 4.7 nF 0805 50 V** from `ISNS_F` to `GND`.

R27/C27 gives 4.7 µs of blanking. The coil takes **2.3 ms** to climb from the 45 A trip to
the 60 A ceiling, so this costs you 0.03 A of overshoot and buys immunity to every switching
edge on the board.

### Check before moving on
- `ISNS` (to the connector) taps at U3 pin 5, **before** R27.
- `ISNS_F` feeds only U4 pin 2 and U4 pin 5.

---

## Block 4 — the connector and the status readback · ~45 min · 1 connector + 6 passives

**Sheet: `io_protect.kicad_sch`.** Findings 8, 9, 19, and the EN pins Block 1 needs.

### Why the connector changes

You need two more pins (EN1, EN2). Single-row Micro-Fit 3.0 stops at 12 circuits, so 13 is
not available in the family. Going to **2×8 (43025-1600)** gets you the pins and lets you put
a ground return next to every fast edge, which is finding 19.

If you would rather not change the connector, the fallback is one board-level EN instead of
two and merging the two status lines — that fits in 12 pins. You lose per-channel enable.
I would take the 16-way.

### New pinout

```
    1  GND        2  GND
    3  PWM_A1     4  PWM_A2
    5  PWM_B1     6  PWM_B2
    7  GND        8  GND
    9  EN1       10  EN2
   11  RESET     12  OK1
   13  GND       14  OK2
   15  ISNS1     16  ISNS2
```

Five grounds. Every PWM line has a ground neighbour. RESET is no longer next to a ground pin,
and even if it shorts to one, Block 1 means the latch can still set on a fault — it just
stops holding. Known remaining weakness: ISNS1 and ISNS2 are adjacent, so a short between
them makes both channels read the same current. Detectable in firmware (identical readings
on two channels is not physical); accepted for rev 0.

### Steps

1. Replace the J202 symbol: `Connector_Generic:Conn_01x12` →
   **`Connector_Generic:Conn_02x08_Odd_Even`**. Footprint → the Micro-Fit 3.0 **2×08**
   horizontal entry in `Connector_Molex` (pick it from the chooser and paste me the exact
   string; I have not verified it against your library). MPN `43025-1600`.
2. Rewire to the pinout above.
3. **Status readback, replacing the FAULT output.** Per channel, the source moves from
   U5 pin 5 (Q) to the `SD_DRV` node from Block 1, and the hierarchical label `FAULT`
   becomes **`OK`** (output). Rename it on both `power_channel` and the root sheet.
   - `R206`: 100 R → **10 k**
   - New **`R233` = 15 k 0805** from `OK1_OUT` to `GND`
   - Same for channel 2: `R207` → 10 k, new **`R234` = 15 k**

   The divider turns 5 V into **3.0 V** at the MCU, which fixes the 9–19 mA injection
   (finding 9). More importantly it inverts the failure sense: **HIGH means healthy.** Board
   unpowered, wire broken, connector unplugged, +5 V lost — all pull the line low through the
   15 k, and all read as *not healthy*. That is finding 8, for two resistors.

   Ask firmware to enable an internal pulldown on that pin so a broken wire also reads low.

4. **EN inputs.** Per channel, mirroring how RESET is done today:
   - **R235 = 100 R** in series from J202 pin 9 → `EN1`
   - **R237 = 10 k** from `EN1` to `GND` ← this is the part that matters. Unplugged,
     unbooted, or crashed MCU means EN low means genuine tri-state.
   - Same for channel 2: **R236 = 100 R**, **R238 = 10 k**, J202 pin 10 → `EN2`
5. Add hierarchical labels `EN1` / `EN2` (output from this sheet's point of view — they leave
   IO_PROTECT and enter the channels via the root).

---

## Block 5 — root sheet · ~10 min

1. Open the root sheet, click each of the CH1 and CH2 sheet symbols, **Update sheet pins**
   (right-click → Import Sheet Pin, or the sync command) so the new `EN` pin appears.
2. Draw the stubs and local labels exactly as the existing ones: `EN1` to CH1's EN pin,
   `EN2` to CH2's EN pin, matching labels on the IO_PROTECT sheet symbol.
3. Same for the renamed `OK` pin, which replaces `FAULT` on both channels.

---

## Block 6 — BUS sheet · ~10 min · footprint and value edits only

1. **C101–C106 footprint** → `Capacitor_THT:CP_Radial_D16.0mm_P7.50mm`. Confirm the exact
   string in the chooser. Add MPN for a Rubycon ZLH 470 µF 100 V (Ø16 × 31.5, **2.4 A rms**).
   The 2.4 A part rather than a 1.3 A part is what gives the bank 14.4 A instead of 7.9 A,
   which is the difference between margin and no margin — see Block 7.
2. **R101 footprint** → `Resistor_SMD:R_2512_6332Metric`. Value stays 22 k. At 164 mW a 1206
   is at 100 % of its derated rating next to a hot heatsink and fails **open, silently**,
   after which the bus never bleeds. A 2512 runs it at ~16 %.
3. Optional but recommended: a bus-present LED — 60 V → 100 k → LED → GND, ~0.5 mA, 36 mW.
   Two parts, and it means nobody has to trust that the bleed resistor is still alive before
   putting a spanner on the ring terminals.

---

## Block 7 — the decision that is not a schematic edit · ~5 min

**Commit to a modulation scheme and write it down.** This is finding 5, and it is the one
thing on this list that costs nothing and changes the most.

- **Sign-magnitude with the two channels interleaved 180°** → bus ripple ≈ 0, the six cans
  have large margin, and switching loss roughly halves.
- **Locked antiphase, channels in phase** → 52 A of bus ripple against a bank that can do
  14 A at best. The bank has to become polymer or film.

Take sign-magnitude interleaved unless controls give you a specific reason not to. Then add
it to the assumption register in `09_design_sheet_rev0.md` §2 as **A14**, and put it in the
title block, because two sheets of this design currently depend on the answer.

---

## After all blocks

1. **Annotate** → "Keep existing annotations", so only the new parts get numbers.
2. **Expect the `#PWR` duplicate errors again.** U6 brings new power symbols, and per-instance
   power references still do not get made unique by "keep existing." Send me the ERC output
   and I will patch CH2's path references in the file the way we did on 08-13.
3. **ERC.** Expect zero errors. The SW_B/COIL_B naming warning stays.
4. **Update PCB from Schematic (F8).** Expect ~19 more footprints per channel-side, so about
   **194 total**, and zero missing.
5. Tell me and I will re-run the independent netlist cross-check against the new file.
6. Commit.

---

## What is deliberately NOT in this plan

| Item | Why deferred |
|---|---|
| Dead-time margin (finding 16) | Measure on the first board. The escape hatch is an IR21844, so lay out the SOIC-14 land if you want the option for free |
| VS series resistors + Schottkys (finding 15) | Real, standard practice, 8 parts. Add it if you have the appetite — it is the item I would most like to see promoted into this list |
| Bus voltage sense, heatsink NTC (finding 14) | Needs spare MCU pins and a firmware conversation first |
| TVS / FET voltage class (finding 13) | Needs the slow-decay decision, which is a design task not an edit |
| Reverse-polarity protection (finding 18) | System-level; belongs with the harness and the pack |
| Watchdog, isolation, DC-link current sense | Rev 1 |

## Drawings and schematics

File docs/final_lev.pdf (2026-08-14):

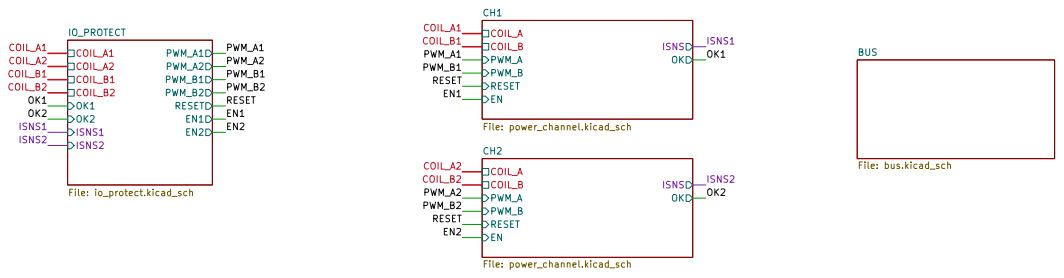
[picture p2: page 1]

Size: A3 | Rev: | F Date:
KiCad E.D.A. 10.0.5 | Id: 1/5

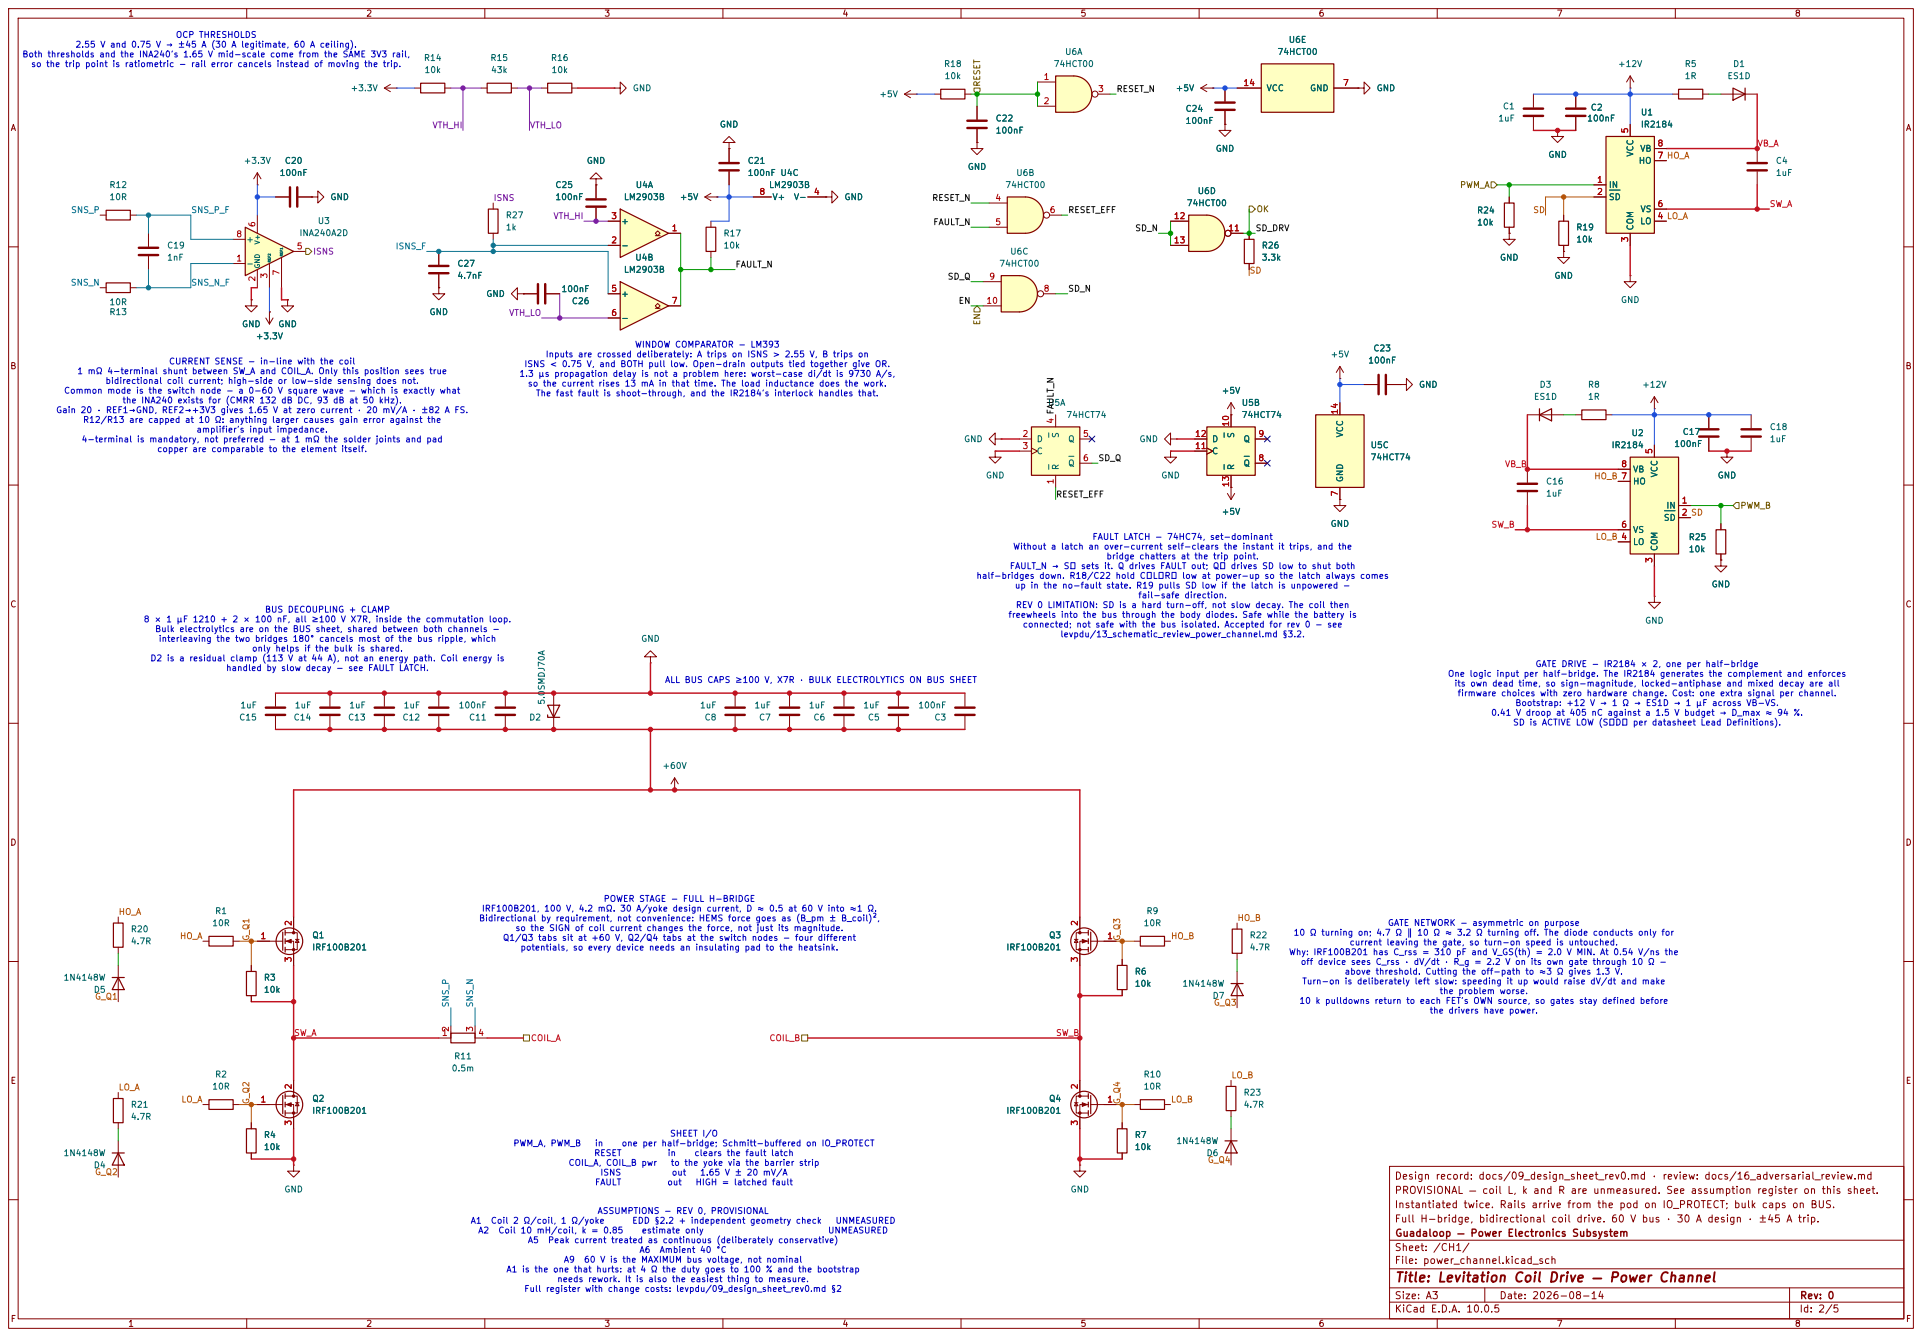
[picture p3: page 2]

2.55 V and 0.75 V → ±45 A (30 A legitimate, 60 A ceiling). Both thresholds and the INA240's 1.65 V mid-scale come from the SAME 3V3 rail, so the trip point is ratiometric - rail error cancels instead of moving the trip.

RESET_EFF CURRENT SENSE - in-line with the coil 1 mΩ 4-terminal shunt between SW_A and COIL_A. Only this position sees true bidirectional coil current; high-side or low-side sensing does not. Common mode is the switch node - a 0-60 V square wave - which is exactly what

Inputs are crossed deliberately: A trips on ISNS > 2.55 V, B trips on

the INA240 exists for (CMRR 132 dB DC, 93 dB at 50 kHz). Gain 20 · REF1→GND, REF2→+3V3 gives 1.65 V at zero current · 20 mV/A · ±82 A FS. R12/R13 are capped at 10 Ω: anything larger causes gain error against the amplifier's input impedance. 4-terminal is mandatory, not preferred - at 1 mΩ the solder joints and pad

FAULT LATCH - 74HC74, set-dominant Without a latch an over-current self-clears the instant it trips, and the bridge chatters at the trip point. FAULT_N → S̄ sets it. Q drives FAULT out; Q̄ drives SD low to shut both

half-bridges down. R18/C22 hold C̄L̄R̄ low at power-up so the latch always comes up in the no-fault state. R19 pulls SD low if the latch is unpowered -

fail-safe direction. REV 0 LIMITATION: SD is a hard turn-off, not slow decay. The coil then

levpdu/13_schematic_review_power_channel.md §3.2. BUS DECOUPLING + CLAMP

freewheels into the bus through the body diodes. Safe while the battery is connected; not safe with the bus isolated. Accepted for rev 0 - see

8 × 1 µF 1210 + 2 × 100 nF, all ≥100 V X7R, inside the commutation loop. Bulk electrolytics are on the BUS sheet, shared between both channels -

interleaving the two bridges 180° cancels most of the bus ripple, which

the drivers have power. ALL BUS CAPS ≥100 V, X7R · BULK ELECTROLYTICS ON BUS SHEET

its own dead time, so sign-magnitude, locked-antiphase and mixed decay are all firmware choices with zero hardware change. Cost: one extra signal per channel. Bootstrap: +12 V → 1 Ω → ES1D → 1 µF across VB-VS. 0.41 V droop at 405 nC against a 1.5 V budget → D_max ≈ 94 %. SD is ACTIVE LOW (S̄D̄ per datasheet Lead Definitions). GATE NETWORK - asymmetric on purpose 10 Ω turning on; 4.7 Ω ∥ 10 Ω ≈ 3.2 Ω turning off. The diode conducts only for current leaving the gate, so turn-on speed is untouched. Why: IRF100B201 has C_rss = 310 pF and V_GS(th) = 2.0 V MIN. At 0.54 V/ns the off device sees C_rss · dV/dt · R_g = 2.2 V on its own gate through 10 Ω -

IRF100B201, 100 V, 4.2 mΩ. 30 A/yoke design current, D ≈ 0.5 at 60 V into ≈1 Ω. Bidirectional by requirement, not convenience: HEMS force goes as (B_pm ± B_coil)², so the SIGN of coil current changes the force, not just its magnitude.

Q1/Q3 tabs sit at +60 V, Q2/Q4 tabs at the switch nodes - four different potentials, so every device needs an insulating pad to the heatsink.

above threshold. Cutting the off-path to ≈3 Ω gives 1.3 V. Turn-on is deliberately left slow: speeding it up would raise dV/dt and make

the problem worse. 10 k pulldowns return to each FET's OWN source, so gates stay defined before

Design record: docs/09_design_sheet_rev0.md · review: docs/16_adversarial_review.md
PROVISIONAL — coil L, k and R are unmeasured. See assumption register on this sheet.
Instantiated twice. Rails arrive from the pod on IO_PROTECT; bulk caps on BUS.
Full H-bridge, bidirectional coil drive. 60 V bus · 30 A design · ±45 A trip.
Guadaloop — Power Electronics Subsystem
Sheet: /CH1/
File: power_channel.kicad_sch
Title: Levitation Coil Drive — Power Channel

A5 Peak current treated as continuous (deliberately conservative) A6 Ambient 40 °C

A9 60 V is the MAXIMUM bus voltage, not nominal A1 is the one that hurts: at 4 Ω the duty goes to 100 % and the bootstrap

needs rework. It is also the easiest thing to measure. Full register with change costs: levpdu/09_design_sheet_rev0.md §2

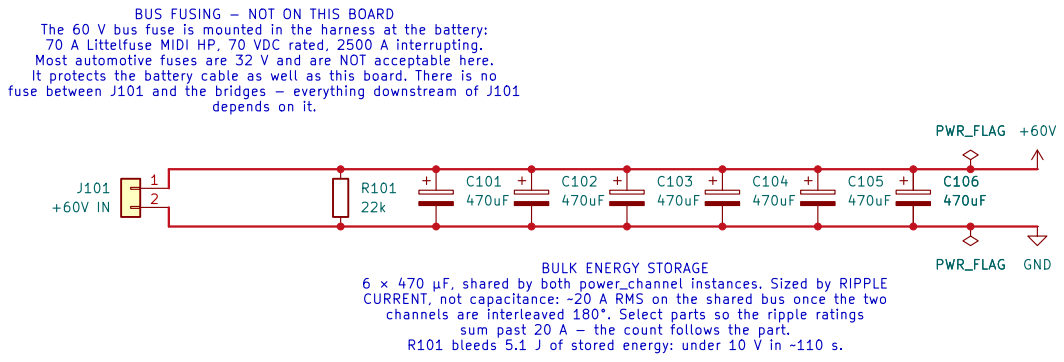
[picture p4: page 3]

sum past 20 A - the count follows the part. R101 bleeds 5.1 J of stored energy: under 10 V in ~110 s. BUS FUSING - NOT ON THIS BOARD

The 60 V bus fuse is mounted in the harness at the battery: 70 A Littelfuse MIDI HP, 70 VDC rated, 2500 A interrupting. Most automotive fuses are 32 V and are NOT acceptable here.

It protects the battery cable as well as this board. There is no
fuse between J101 and the bridges - everything downstream of J101
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

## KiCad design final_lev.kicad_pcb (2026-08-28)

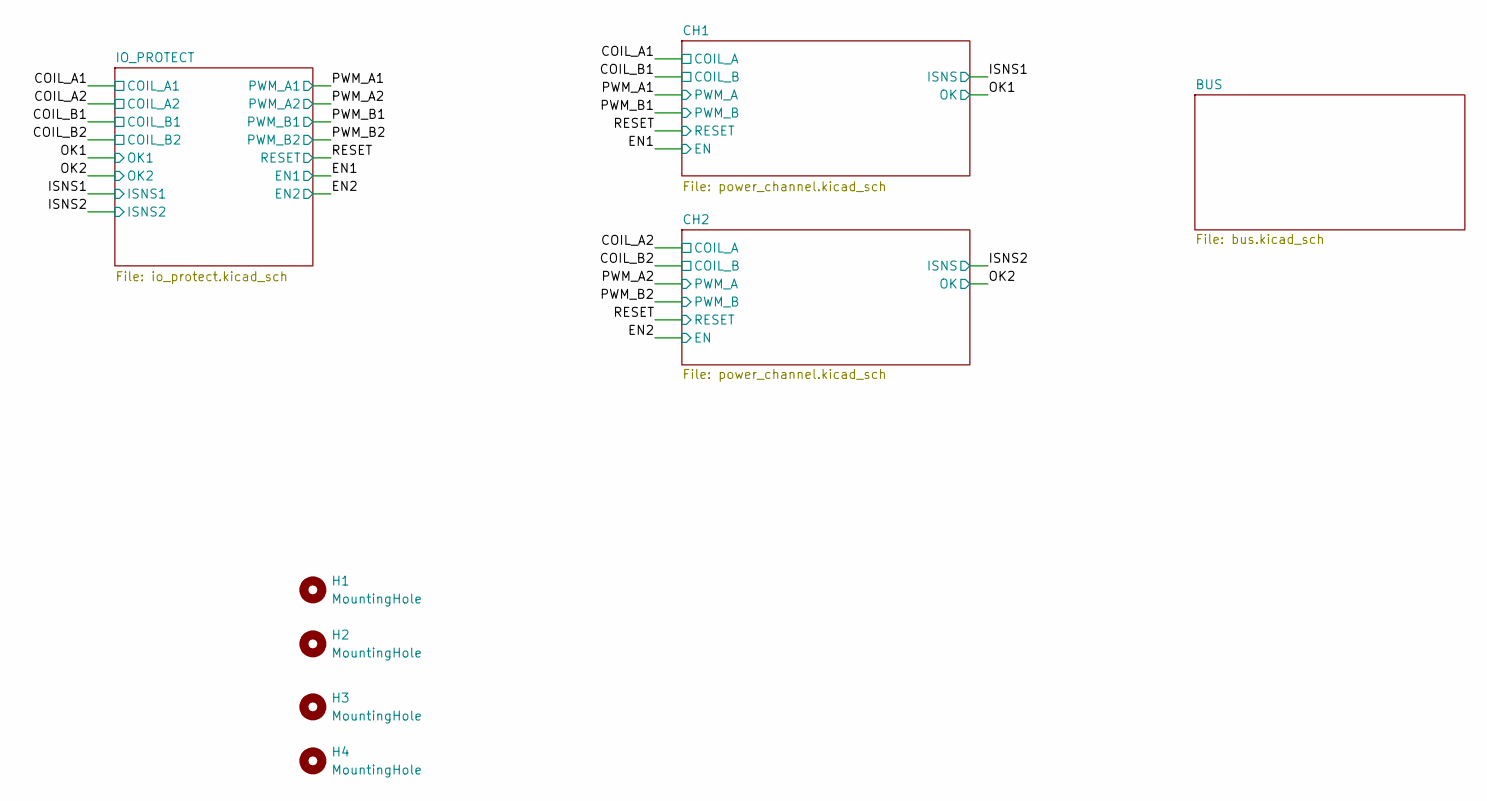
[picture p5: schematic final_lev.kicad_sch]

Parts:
H1, H2, H3, H4: MountingHole; MountingHole_3.2mm_M3_Pad

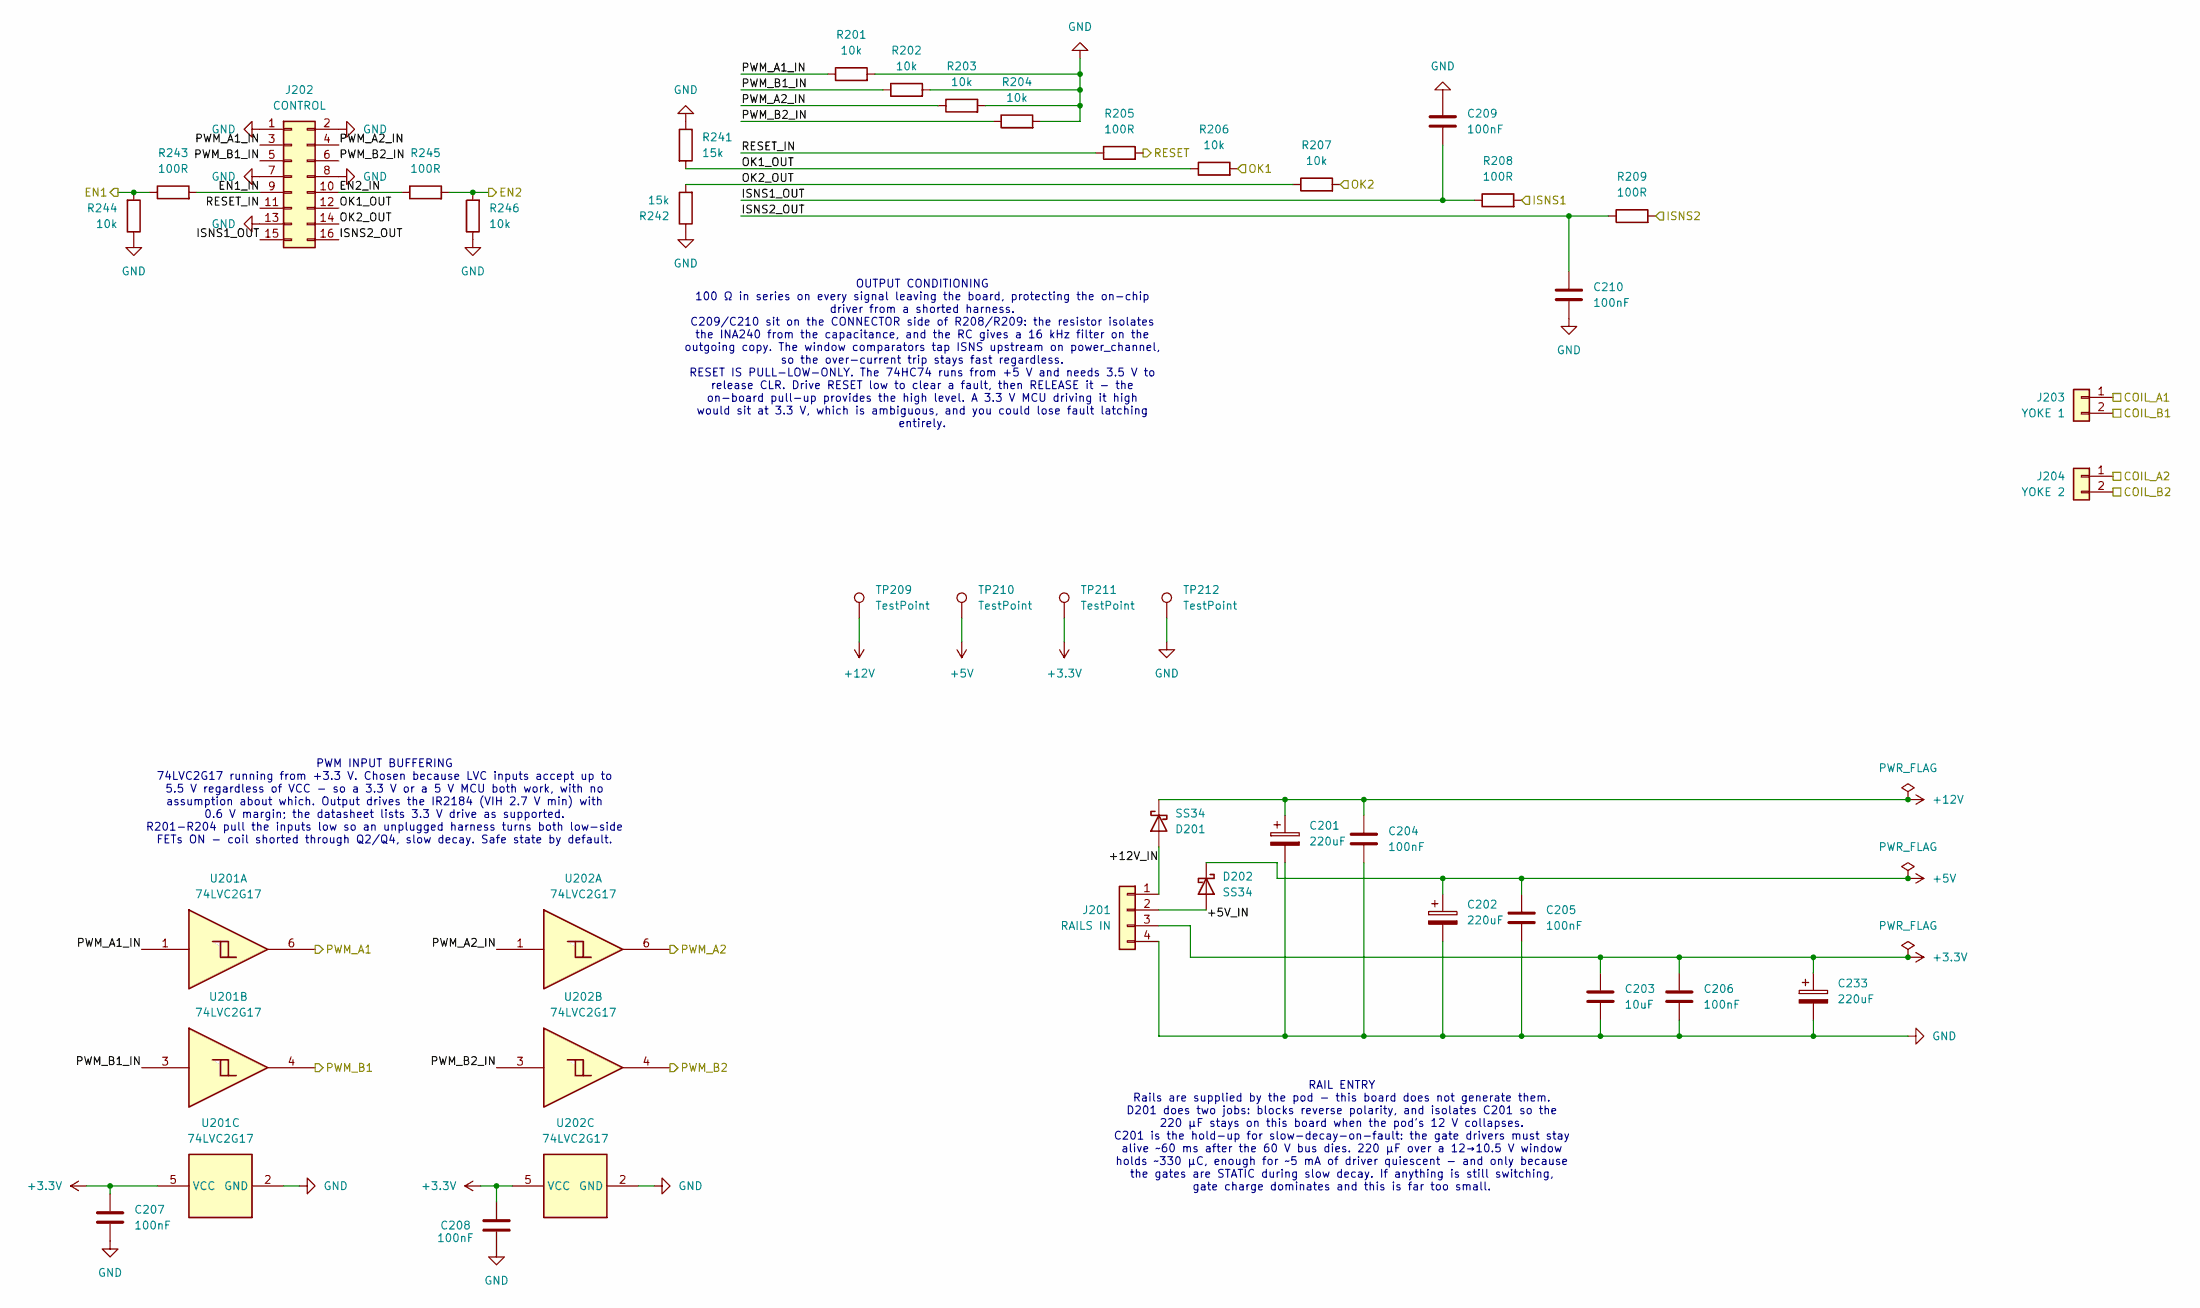
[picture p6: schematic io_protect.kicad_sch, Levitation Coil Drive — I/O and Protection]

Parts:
C201, C202, C233: 220uF; CP_Radial_D8.0mm_P3.50mm; Voltage 25V
C203: 10uF; C_1206_3216Metric_Pad1.33x1.80mm_HandSolder; Voltage 25V
C204, C205, C206, C207, C208, C209, C210: 100nF; C_0805_2012Metric_Pad1.18x1.45mm_HandSolder; Voltage 25V
D201, D202: SS34; D_SMA_Handsoldering
J201: RAILS IN; Molex_Micro-Fit_3.0_43650-0400_1x04_P3.00mm_Horizontal; MPN 43650-0400
J202: CONTROL; Molex_Micro-Fit_3.0_43045-1600_2x08_P3.00mm_Horizontal; MPN 43045-1600
J203: YOKE 1; 389690002; MPN 38969-0002
J204: YOKE 2; 389690002; MPN 38969-0002
R201, R202, R203, R204, R206, R207, R244, R246: 10k; R_0805_2012Metric_Pad1.20x1.40mm_HandSolder
R205, R208, R209, R243, R245: 100R; R_0805_2012Metric_Pad1.20x1.40mm_HandSolder
R241, R242: 15k; R_0805_2012Metric_Pad1.20x1.40mm_HandSolder
TP209, TP210, TP211, TP212: TestPoint; TestPoint_Loop_D2.50mm_Drill1.0mm
U201, U202: 74LVC2G17; SOT-23-6

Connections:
+3.3V: C203.1, C206.1, C207.1, C208.1, C233.1, J201.3, TP211.1 (1_1), U201.5 (VCC), U202.5 (VCC); also elsewhere on the board
+5V: C202.1, C205.1, D202.1 (K), TP210.1 (1_1); also elsewhere on the board
+12V: C201.1, C204.1, D201.1 (K), TP209.1 (1_1); also elsewhere on the board
/COIL_A1: J203.1; also elsewhere on the board
/COIL_A2: J204.1; also elsewhere on the board
/COIL_B1: J203.2; also elsewhere on the board
/COIL_B2: J204.2; also elsewhere on the board
/EN1: R243.1, R244.2; also elsewhere on the board
/EN2: R245.2, R246.2; also elsewhere on the board
/IO_PROTECT/+5V_IN: D202.2 (A), J201.2
/IO_PROTECT/+12V_IN: D201.2 (A), J201.1
/IO_PROTECT/EN1_IN: J202.9, R243.2
/IO_PROTECT/EN2_IN: J202.10, R245.1
/IO_PROTECT/ISNS1_OUT: C209.2, J202.15, R208.1
/IO_PROTECT/ISNS2_OUT: C210.1, J202.16, R209.1
/IO_PROTECT/OK1_OUT: J202.12, R206.1, R241.2
/IO_PROTECT/OK2_OUT: J202.14, R207.1, R242.2
/IO_PROTECT/PWM_A1_IN: J202.3, R201.1, U201.1
/IO_PROTECT/PWM_A2_IN: J202.4, R203.1, U202.1
/IO_PROTECT/PWM_B1_IN: J202.5, R202.1, U201.3
/IO_PROTECT/PWM_B2_IN: J202.6, R204.1, U202.3
/IO_PROTECT/RESET_IN: J202.11, R205.1
/ISNS1: R208.2; also elsewhere on the board
/ISNS2: R209.2; also elsewhere on the board
/OK1: R206.2; also elsewhere on the board
/OK2: R207.2; also elsewhere on the board
/PWM_A1: U201.6; also elsewhere on the board
/PWM_A2: U202.6; also elsewhere on the board
/PWM_B1: U201.4; also elsewhere on the board
/PWM_B2: U202.4; also elsewhere on the board
/RESET: R205.2; also elsewhere on the board
GND: C201.2, C202.2, C203.2, C204.2, C205.2, C206.2, C207.2, C208.2, C209.1, C210.2, C233.2, J201.4, J202.1, J202.2, J202.7, J202.8, J202.13, R201.2, R202.2, R203.2, R204.2, R241.1, R242.1, R244.1, R246.1, TP212.1 (1_1), U201.2 (GND), U202.2 (GND); also elsewhere on the board

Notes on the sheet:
PWM INPUT BUFFERING 74LVC2G17 running from +3.3 V. Chosen because LVC inputs accept up to 5.5 V regardless of VCC - so a 3.3 V or a 5 V MCU both work, with no assumption about which. Output drives the IR2184 (VIH 2.7 V min) with 0.6 V margin; the datasheet lists 3.3 V drive as supported. R201-R204 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
RAIL ENTRY Rails are supplied by the pod - this board does not generate them. D201 does two jobs: blocks reverse polarity, and isolates C201 so the 220 µF stays on this board when the pod's 12 V collapses. C201 is the hold-up for slow-decay-on-fault: the gate drivers must stay alive ~60 ms after th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
OUTPUT CONDITIONING 100 Ω in series on every signal leaving the board, protecting the on-chip driver from a shorted harness. C209/C210 sit on the CONNECTOR side of R208/R209: the resistor isolates the INA240 from the capacitance, and the RC gives a 16 kHz filter on the outgoing copy. The window com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

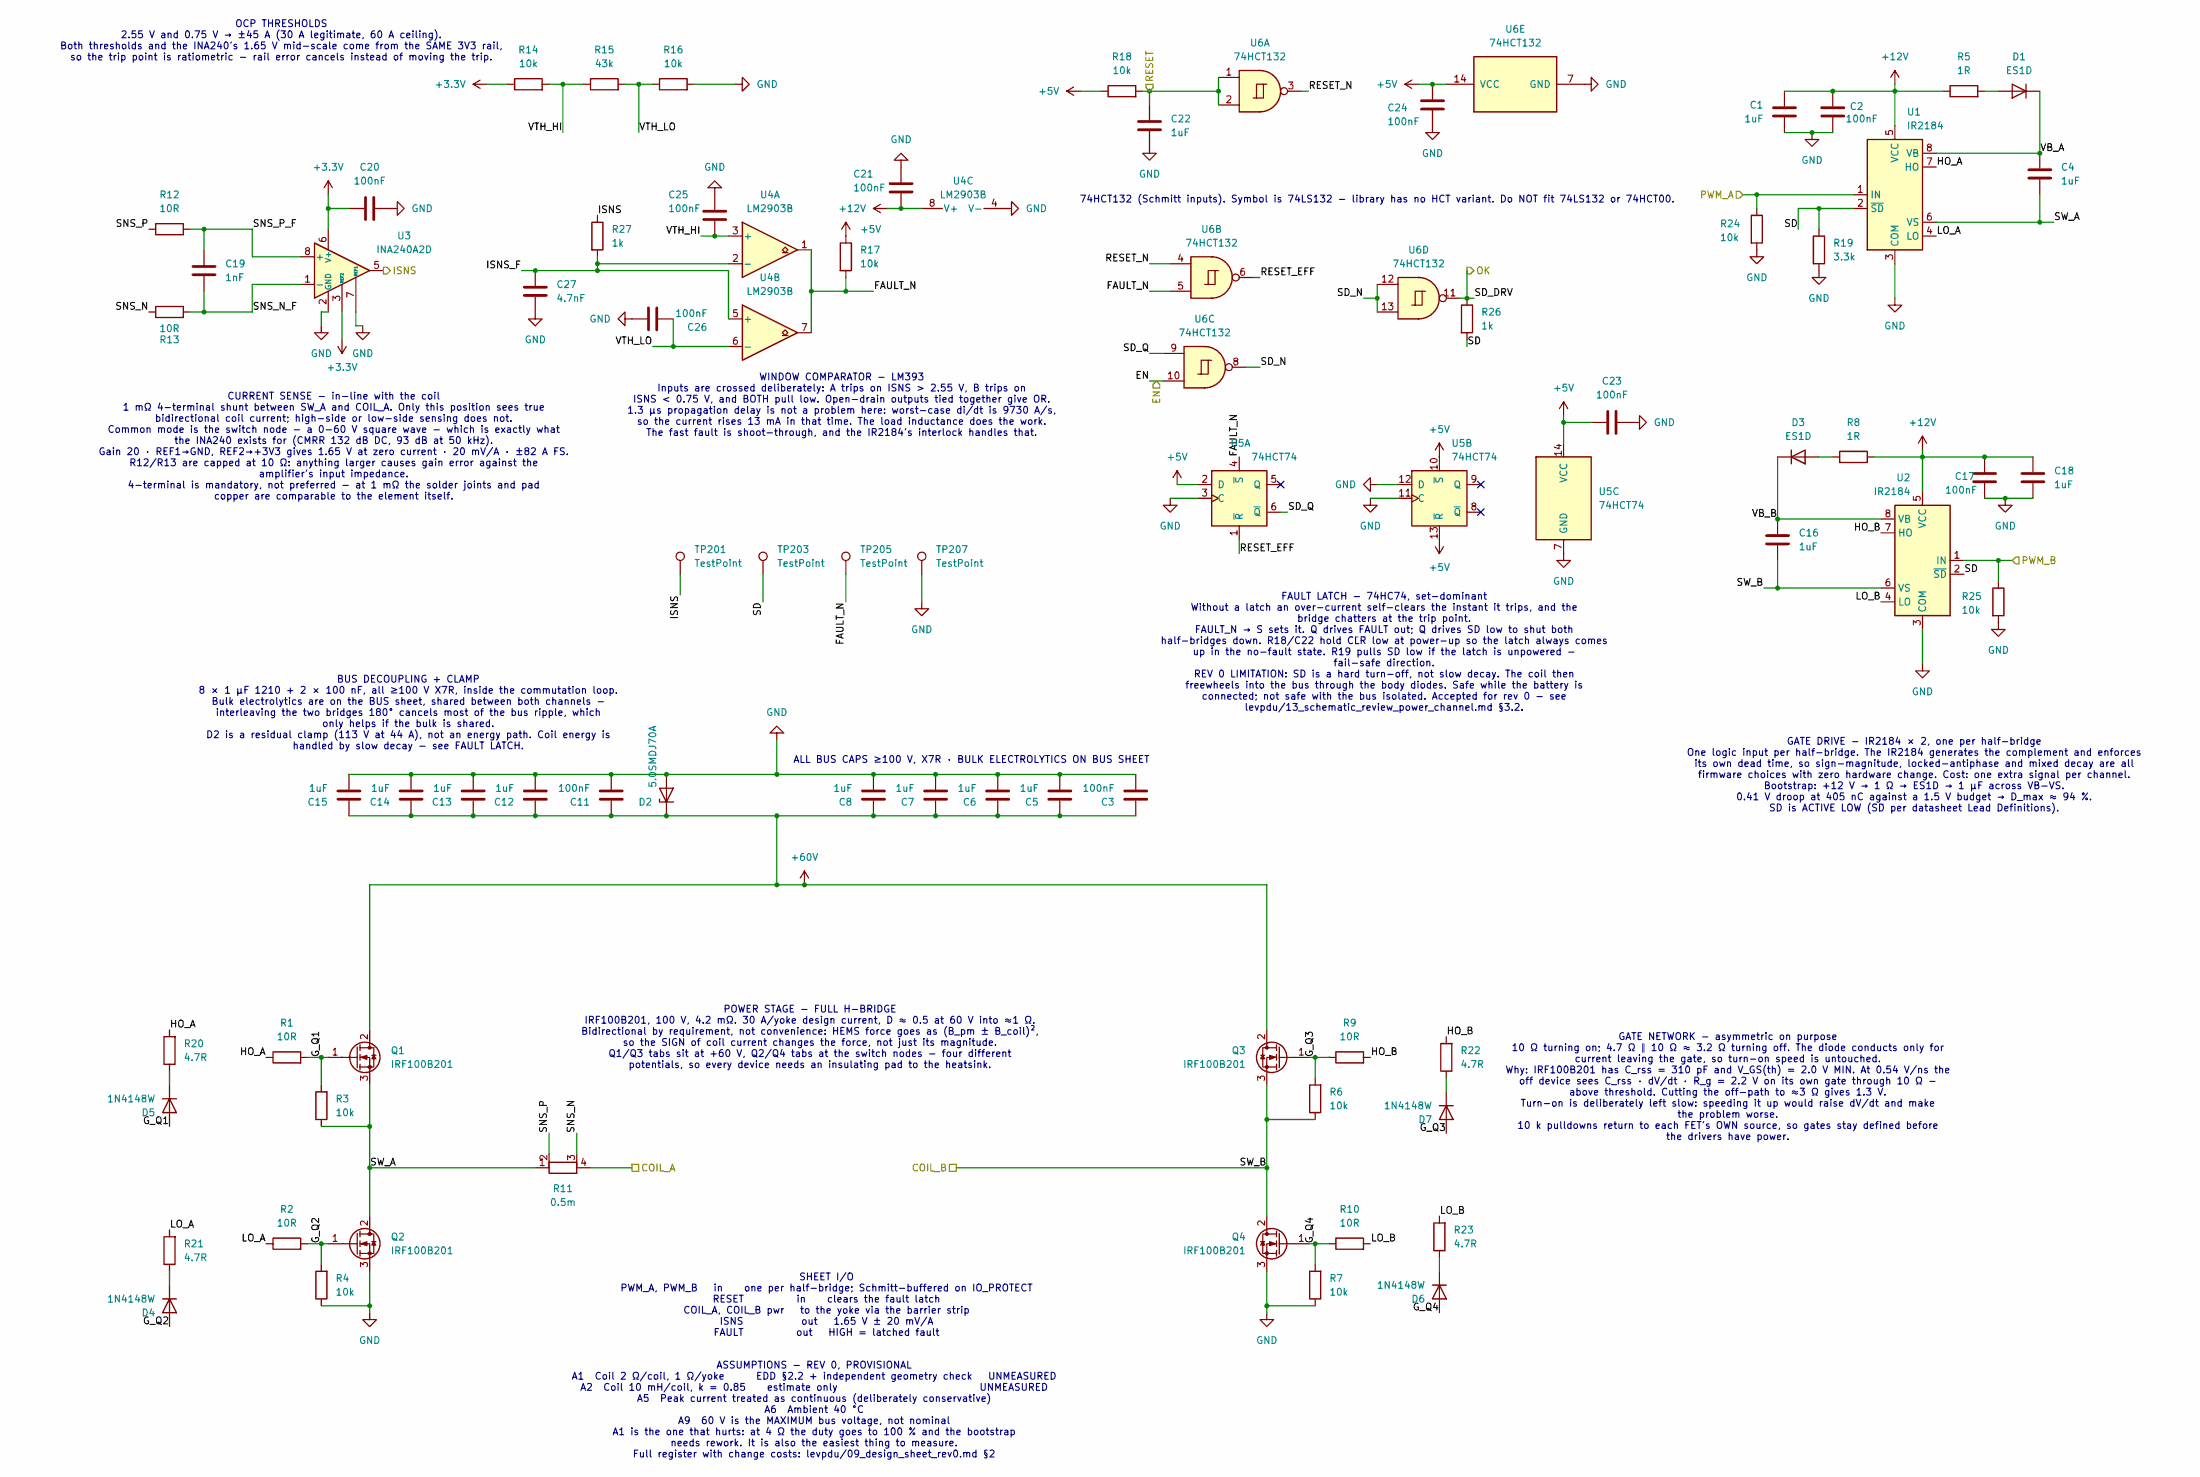
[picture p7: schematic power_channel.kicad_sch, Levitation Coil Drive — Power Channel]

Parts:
C1, C4, C16, C18, C22: 1uF; C_0805_2012Metric_Pad1.18x1.45mm_HandSolder; Voltage 25V
C2, C3, C11, C17, C20, C21, C23: 100nF; C_0805_2012Metric_Pad1.18x1.45mm_HandSolder; Voltage 100V
C5, C6, C7, C8, C12, C13, C14, C15: 1uF; C_1210_3225Metric_Pad1.33x2.70mm_HandSolder; Voltage 100V
C19: 1nF; C_0805_2012Metric_Pad1.18x1.45mm_HandSolder; Voltage 50V
C24, C25, C26: 100nF; C_0805_2012Metric_Pad1.18x1.45mm_HandSolder; Voltage 25V
C27: 4.7nF; C_0805_2012Metric_Pad1.18x1.45mm_HandSolder; Voltage 50V
D1, D3: ES1D; D_SMA_Handsoldering
D2: 5.0SMDJ70A; D_SMC_Handsoldering
D4, D5, D6, D7: 1N4148W; D_SOD-123
Q1, Q2, Q3, Q4: IRF100B201; TO-220-3_Vertical; MPN IRF100B201
R1, R2, R9, R10: 10R; R_1206_3216Metric_Pad1.30x1.75mm_HandSolder
R3, R4, R6, R7, R17, R18, R24, R25: 10k; R_0805_2012Metric_Pad1.20x1.40mm_HandSolder
R5, R8: 1R; R_0805_2012Metric_Pad1.20x1.40mm_HandSolder
R11: 0.5m; R_Shunt_Vishay_WSK2512_6332Metric_T2.66mm; Tolerance 1%; MPN WSK2512L5000FEA
R12, R13: 10R; R_0805_2012Metric_Pad1.20x1.40mm_HandSolder
R14, R16: 10k; R_0805_2012Metric_Pad1.20x1.40mm_HandSolder; Tolerance 1%
R15: 43k; R_0805_2012Metric_Pad1.20x1.40mm_HandSolder; Tolerance 1%
R19: 3.3k; R_0805_2012Metric_Pad1.20x1.40mm_HandSolder
R20, R21, R22, R23: 4.7R; R_0805_2012Metric_Pad1.20x1.40mm_HandSolder
R26, R27: 1k; R_0805_2012Metric_Pad1.20x1.40mm_HandSolder
TP201, TP203, TP205, TP207: TestPoint; TestPoint_Loop_D2.50mm_Drill1.0mm
U1, U2: IR2184; SOIC-8_3.9x4.9mm_P1.27mm; MPN IR2184SPBF
U3: INA240A2D; SOIC-8_3.9x4.9mm_P1.27mm
U4: LM2903B; SOIC-8_3.9x4.9mm_P1.27mm; MPN LM2903BDR
U5: 74HCT74; SOIC-14_3.9x8.7mm_P1.27mm
U6: 74HCT132; SOIC-14_3.9x8.7mm_P1.27mm; MPN 74HCT132D,653

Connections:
+3.3V: C20.1, R14.1, U3.3 (REF2), U3.6 (V+); also elsewhere on the board
+5V: C23.1, C24.1, R17.1, R18.1, U5.2 (D), U5.10 (~S), U5.13 (~R), U5.14 (VCC), U6.14 (VCC); also elsewhere on the board
+12V: C1.1, C2.1, C17.1, C18.1, C21.2, R5.1, R8.1, U1.5 (VCC), U2.5 (VCC), U4.8 (V+); also elsewhere on the board
+60V: C3.1, C5.1, C6.1, C7.1, C8.1, C11.1, C12.1, C13.1, C14.1, C15.1, D2.1 (K), Q1.2 (D), Q3.2 (D); also elsewhere on the board
/CH1/FAULT_N: R17.2, TP205.1 (1_1), U4.1, U4.7, U5.4 (~S), U6.5
/CH1/G_Q1: D5.2 (A), Q1.1 (G), R1.2, R3.2
/CH1/G_Q2: D4.2 (A), Q2.1 (G), R2.2, R4.2
/CH1/G_Q3: D7.2 (A), Q3.1 (G), R6.2, R9.1
/CH1/G_Q4: D6.2 (A), Q4.1 (G), R7.2, R10.1
/CH1/HO_A: R1.1, R20.2, U1.7 (HO)
/CH1/HO_B: R9.2, R22.2, U2.7 (HO)
/CH1/ISNS_F: C27.1, R27.2, U4.2 (-), U4.5 (+)
/CH1/LO_A: R2.1, R21.2, U1.4 (LO)
/CH1/LO_B: R10.2, R23.2, U2.4 (LO)
/CH1/RESET_EFF: U5.1 (~R), U6.6
/CH1/RESET_N: U6.3, U6.4
/CH1/SD: R19.1, R26.2, TP203.1 (1_1), U1.2 (~SD), U2.2 (~SD)
/CH1/SD_N: U6.8, U6.12, U6.13
/CH1/SD_Q: U5.6 (~Q), U6.9
/CH1/SNS_N: R11.3, R13.1
/CH1/SNS_N_F: C19.2, R13.2, U3.1 (-)
/CH1/SNS_P: R11.2, R12.1
/CH1/SNS_P_F: C19.1, R12.2, U3.8 (+)
/CH1/SW_A: C4.2, Q1.3 (S), Q2.2 (D), R3.1, R11.1, U1.6 (VS)
/CH1/VB_A: C4.1, D1.1 (K), U1.8 (VB)
/CH1/VB_B: C16.1, D3.1 (K), U2.8 (VB)
/CH1/VTH_HI: C25.2, R14.2, R15.1, U4.3 (+)
/CH1/VTH_LO: C26.2, R15.2, R16.1, U4.6 (-)
/COIL_A1: R11.4; also elsewhere on the board
/COIL_B1: C16.2, Q3.3 (S), Q4.2 (D), R6.1, U2.6 (VS); also elsewhere on the board
/EN1: U6.10; also elsewhere on the board
/ISNS1: R27.1, TP201.1 (1_1), U3.5; also elsewhere on the board
/OK1: R26.1, U6.11; also elsewhere on the board
/PWM_A1: R24.1, U1.1 (IN); also elsewhere on the board
/PWM_B1: R25.1, U2.1 (IN); also elsewhere on the board
/RESET: C22.1, R18.2, U6.1, U6.2; also elsewhere on the board
GND: C1.2, C2.2, C3.2, C5.2, C6.2, C7.2, C8.2, C11.2, C12.2, C13.2, C14.2, C15.2, C17.2, C18.2, C20.2, C21.1, C22.2, C23.2, C24.2, C25.1, C26.1, C27.2, D2.2 (A), Q2.3 (S), Q4.3 (S), R4.1, R7.1, R16.2, R19.2, R24.2, R25.2, TP207.1 (1_1), U1.3 (COM), U2.3 (COM), U3.2 (GND), U3.4 (GND), U3.7 (REF1), U4.4 (V-), U5.3 (C), U5.7 (GND), U5.11 (C), U5.12 (D), U6.7 (GND); also elsewhere on the board
unnamed: D1.2 (A), R5.2
unnamed: D3.2 (A), R8.2
unnamed: D4.1 (K), R21.1
unnamed: D5.1 (K), R20.1
unnamed: D6.1 (K), R23.1
unnamed: D7.1 (K), R22.1

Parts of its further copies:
C211: 1nF; C_0805_2012Metric_Pad1.18x1.45mm_HandSolder; Voltage 50V
C212, C214, C215, C216, C219, C220, C221, C222: 1uF; C_1210_3225Metric_Pad1.33x2.70mm_HandSolder; Voltage 100V
C213, C217, C218, C223, C225, C228, C229: 100nF; C_0805_2012Metric_Pad1.18x1.45mm_HandSolder; Voltage 100V
C224, C226, C227, C230, C231: 1uF; C_0805_2012Metric_Pad1.18x1.45mm_HandSolder; Voltage 25V
C232, C235, C237: 100nF; C_0805_2012Metric_Pad1.18x1.45mm_HandSolder; Voltage 25V
C239: 4.7nF; C_0805_2012Metric_Pad1.18x1.45mm_HandSolder; Voltage 50V
D203, D204, D206, D207: 1N4148W; D_SOD-123
D205: 5.0SMDJ70A; D_SMC_Handsoldering
D208, D209: ES1D; D_SMA_Handsoldering
Q201, Q202, Q203, Q204: IRF100B201; TO-220-3_Vertical; MPN IRF100B201
R210, R211: 10R; R_0805_2012Metric_Pad1.20x1.40mm_HandSolder
R212, R213, R228, R229: 4.7R; R_0805_2012Metric_Pad1.20x1.40mm_HandSolder
R214, R215, R226, R227: 10R; R_1206_3216Metric_Pad1.30x1.75mm_HandSolder
R216, R217, R222, R223, R224, R225, R236, R238: 10k; R_0805_2012Metric_Pad1.20x1.40mm_HandSolder
R218, R221: 10k; R_0805_2012Metric_Pad1.20x1.40mm_HandSolder; Tolerance 1%
R219: 0.5m; R_Shunt_Vishay_WSK2512_6332Metric_T2.66mm; Tolerance 1%; MPN WSK2512L5000FEA
R220: 43k; R_0805_2012Metric_Pad1.20x1.40mm_HandSolder; Tolerance 1%
R230: 3.3k; R_0805_2012Metric_Pad1.20x1.40mm_HandSolder
R231, R232: 1R; R_0805_2012Metric_Pad1.20x1.40mm_HandSolder
R234, R240: 1k; R_0805_2012Metric_Pad1.20x1.40mm_HandSolder
TP202, TP204, TP206, TP208: TestPoint; TestPoint_Loop_D2.50mm_Drill1.0mm
U203: INA240A2D; SOIC-8_3.9x4.9mm_P1.27mm
U204: LM2903B; SOIC-8_3.9x4.9mm_P1.27mm; MPN LM2903BDR
U205: 74HCT74; SOIC-14_3.9x8.7mm_P1.27mm
U206, U207: IR2184; SOIC-8_3.9x4.9mm_P1.27mm; MPN IR2184SPBF
U208: 74HCT132; SOIC-14_3.9x8.7mm_P1.27mm; MPN 74HCT132D,653

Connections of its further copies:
+3.3V: C213.1, R218.1, U203.3 (REF2), U203.6 (V+); also elsewhere on the board
+5V: C225.1, C232.1, R222.1, R223.1, U205.2 (D), U205.10 (~S), U205.13 (~R), U205.14 (VCC), U208.14 (VCC); also elsewhere on the board
+12V: C218.2, C227.1, C228.1, C229.1, C230.1, R231.1, R232.1, U204.8 (V+), U206.5 (VCC), U207.5 (VCC); also elsewhere on the board
+60V: C212.1, C214.1, C215.1, C216.1, C217.1, C219.1, C220.1, C221.1, C222.1, C223.1, D205.1 (K), Q201.2 (D), Q203.2 (D); also elsewhere on the board
/CH2/FAULT_N: R222.2, TP206.1 (1_1), U204.1, U204.7, U205.4 (~S), U208.5
/CH2/G_Q1: D203.2 (A), Q201.1 (G), R214.2, R216.2
/CH2/G_Q2: D204.2 (A), Q202.1 (G), R215.2, R217.2
/CH2/G_Q3: D207.2 (A), Q203.1 (G), R224.2, R226.1
/CH2/G_Q4: D206.2 (A), Q204.1 (G), R225.2, R227.1
/CH2/HO_A: R212.2, R214.1, U206.7 (HO)
/CH2/HO_B: R226.2, R229.2, U207.7 (HO)
/CH2/ISNS_F: C239.1, R240.2, U204.2 (-), U204.5 (+)
/CH2/LO_A: R213.2, R215.1, U206.4 (LO)
/CH2/LO_B: R227.2, R228.2, U207.4 (LO)
/CH2/RESET_EFF: U205.1 (~R), U208.6
/CH2/RESET_N: U208.3, U208.4
/CH2/SD: R230.1, R234.2, TP204.1 (1_1), U206.2 (~SD), U207.2 (~SD)
/CH2/SD_N: U208.8, U208.12, U208.13
/CH2/SD_Q: U205.6 (~Q), U208.9
/CH2/SNS_N: R211.1, R219.3
/CH2/SNS_N_F: C211.2, R211.2, U203.1 (-)
/CH2/SNS_P: R210.1, R219.2
/CH2/SNS_P_F: C211.1, R210.2, U203.8 (+)
/CH2/SW_A: C231.2, Q201.3 (S), Q202.2 (D), R216.1, R219.1, U206.6 (VS)
/CH2/VB_A: C231.1, D209.1 (K), U206.8 (VB)
/CH2/VB_B: C226.1, D208.1 (K), U207.8 (VB)
/CH2/VTH_HI: C235.2, R218.2, R220.1, U204.3 (+)
/CH2/VTH_LO: C237.2, R220.2, R221.1, U204.6 (-)
/COIL_A2: R219.4; also elsewhere on the board
/COIL_B2: C226.2, Q203.3 (S), Q204.2 (D), R224.1, U207.6 (VS); also elsewhere on the board
/EN2: U208.10; also elsewhere on the board
/ISNS2: R240.1, TP202.1 (1_1), U203.5; also elsewhere on the board
/OK2: R234.1, U208.11; also elsewhere on the board
/PWM_A2: R236.1, U206.1 (IN); also elsewhere on the board
/PWM_B2: R238.1, U207.1 (IN); also elsewhere on the board
/RESET: C224.1, R223.2, U208.1, U208.2; also elsewhere on the board
GND: C212.2, C213.2, C214.2, C215.2, C216.2, C217.2, C218.1, C219.2, C220.2, C221.2, C222.2, C223.2, C224.2, C225.2, C227.2, C228.2, C229.2, C230.2, C232.2, C235.1, C237.1, C239.2, D205.2 (A), Q202.3 (S), Q204.3 (S), R217.1, R221.2, R225.1, R230.2, R236.2, R238.2, TP208.1 (1_1), U203.2 (GND), U203.4 (GND), U203.7 (REF1), U204.4 (V-), U205.3 (C), U205.7 (GND), U205.11 (C), U205.12 (D), U206.3 (COM), U207.3 (COM), U208.7 (GND); also elsewhere on the board
unnamed: D203.1 (K), R212.1
unnamed: D204.1 (K), R213.1
unnamed: D206.1 (K), R228.1
unnamed: D207.1 (K), R229.1
unnamed: D208.2 (A), R231.2
unnamed: D209.2 (A), R232.2

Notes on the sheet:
ALL BUS CAPS ≥100 V, X7R · BULK ELECTROLYTICS ON BUS SHEET
GATE DRIVE - IR2184 × 2, one per half-bridge One logic input per half-bridge. The IR2184 generates the complement and enforces its own dead time, so sign-magnitude, locked-antiphase and mixed decay are all firmware choices with zero hardware change. Cost: one extra signal per channel. Bootstrap: +1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
ASSUMPTIONS - REV 0, PROVISIONAL A1 Coil 2 Ω/coil, 1 Ω/yoke EDD §2.2 + independent geometry check UNMEASURED A2 Coil 10 mH/coil, k = 0.85 estimate only UNMEASURED A5 Peak current treated as continuous (deliberately conservative) A6 Ambient 40 °C A9 60 V is the MAXIMUM bus voltage, not nominal A1 is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
SHEET I/O PWM_A, PWM_B in one per half-bridge; Schmitt-buffered on IO_PROTECT RESET in clears the fault latch COIL_A, COIL_B pwr to the yoke via the barrier strip ISNS out 1.65 V ± 20 mV/A FAULT out HIGH = latched fault
74HCT132 (Schmitt inputs). Symbol is 74LS132 - library has no HCT variant. Do NOT fit 74LS132 or 74HCT00.
FAULT LATCH - 74HC74, set-dominant Without a latch an over-current self-clears the instant it trips, and the bridge chatters at the trip point. FAULT_N → S̄ sets it. Q drives FAULT out; Q̄ drives SD low to shut both half-bridges down. R18/C22 hold C̄L̄R̄ low at power-up so the latch always comes up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
GATE NETWORK - asymmetric on purpose 10 Ω turning on; 4.7 Ω ∥ 10 Ω ≈ 3.2 Ω turning off. The diode conducts only for current leaving the gate, so turn-on speed is untouched. Why: IRF100B201 has C_rss = 310 pF and V_GS(th) = 2.0 V MIN. At 0.54 V/ns the off device sees C_rss · dV/dt · R_g = 2.2 V on i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
POWER STAGE - FULL H-BRIDGE IRF100B201, 100 V, 4.2 mΩ. 30 A/yoke design current, D ≈ 0.5 at 60 V into ≈1 Ω. Bidirectional by requirement, not convenience: HEMS force goes as (B_pm ± B_coil)², so the SIGN of coil current changes the force, not just its magnitude. Q1/Q3 tabs sit at +60 V, Q2/Q4 tabs 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
WINDOW COMPARATOR - LM393 Inputs are crossed deliberately: A trips on ISNS > 2.55 V, B trips on ISNS < 0.75 V, and BOTH pull low. Open-drain outputs tied together give OR. 1.3 µs propagation delay is not a problem here: worst-case di/dt is 9730 A/s, so the current rises 13 mA in that time. The load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
BUS DECOUPLING + CLAMP 8 × 1 µF 1210 + 2 × 100 nF, all ≥100 V X7R, inside the commutation loop. Bulk electrolytics are on the BUS sheet, shared between both channels - interleaving the two bridges 180° cancels most of the bus ripple, which only helps if the bulk is shared. D2 is a residual clamp (1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
OCP THRESHOLDS 2.55 V and 0.75 V → ±45 A (30 A legitimate, 60 A ceiling). Both thresholds and the INA240's 1.65 V mid-scale come from the SAME 3V3 rail, so the trip point is ratiometric - rail error cancels instead of moving the trip.
CURRENT SENSE - in-line with the coil 1 mΩ 4-terminal shunt between SW_A and COIL_A. Only this position sees true bidirectional coil current; high-side or low-side sensing does not. Common mode is the switch node - a 0-60 V square wave - which is exactly what the INA240 exists for (CMRR 132 dB DC, 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

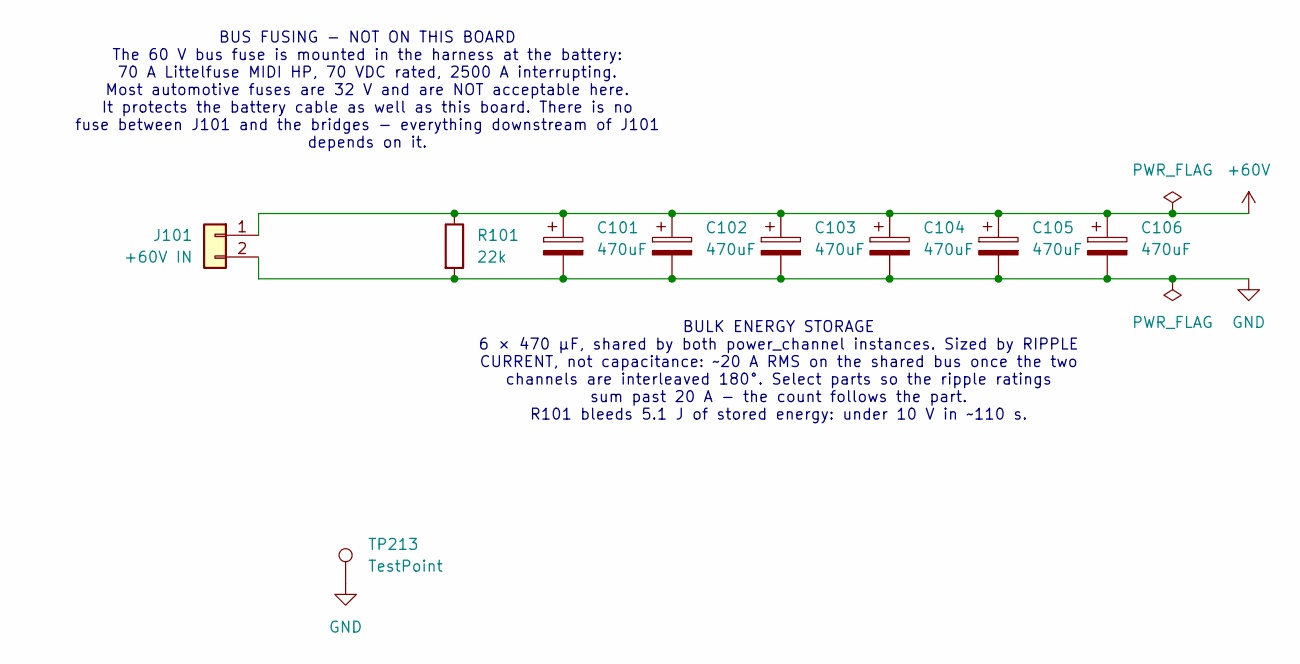
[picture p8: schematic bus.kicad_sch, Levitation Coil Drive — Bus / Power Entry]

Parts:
C101, C102, C103, C104, C105, C106: 470uF; CP_Radial_D16.0mm_P7.50mm; Voltage 100V; MPN 100ZLH470MEFC16X31.5
J101: +60V IN; 389690002; MPN 38969-0002
R101: 22k; R_2512_6332Metric
TP213: TestPoint; TestPoint_Loop_D2.50mm_Drill1.0mm

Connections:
+60V: C101.1, C102.1, C103.1, C104.1, C105.1, C106.1, J101.1, R101.1; also elsewhere on the board
GND: C101.2, C102.2, C103.2, C104.2, C105.2, C106.2, J101.2, R101.2, TP213.1 (1_1); also elsewhere on the board

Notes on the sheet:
BUS FUSING - NOT ON THIS BOARD The 60 V bus fuse is mounted in the harness at the battery: 70 A Littelfuse MIDI HP, 70 VDC rated, 2500 A interrupting. Most automotive fuses are 32 V and are NOT acceptable here. It protects the battery cable as well as this board. There is no fuse between J101 and t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
BULK ENERGY STORAGE 6 × 470 µF, shared by both power_channel instances. Sized by RIPPLE CURRENT, not capacitance: ~20 A RMS on the shared bus once the two channels are interleaved 180°. Select parts so the ripple ratings sum past 20 A - the count follows the part. R101 bleeds 5.1 J of stored energy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

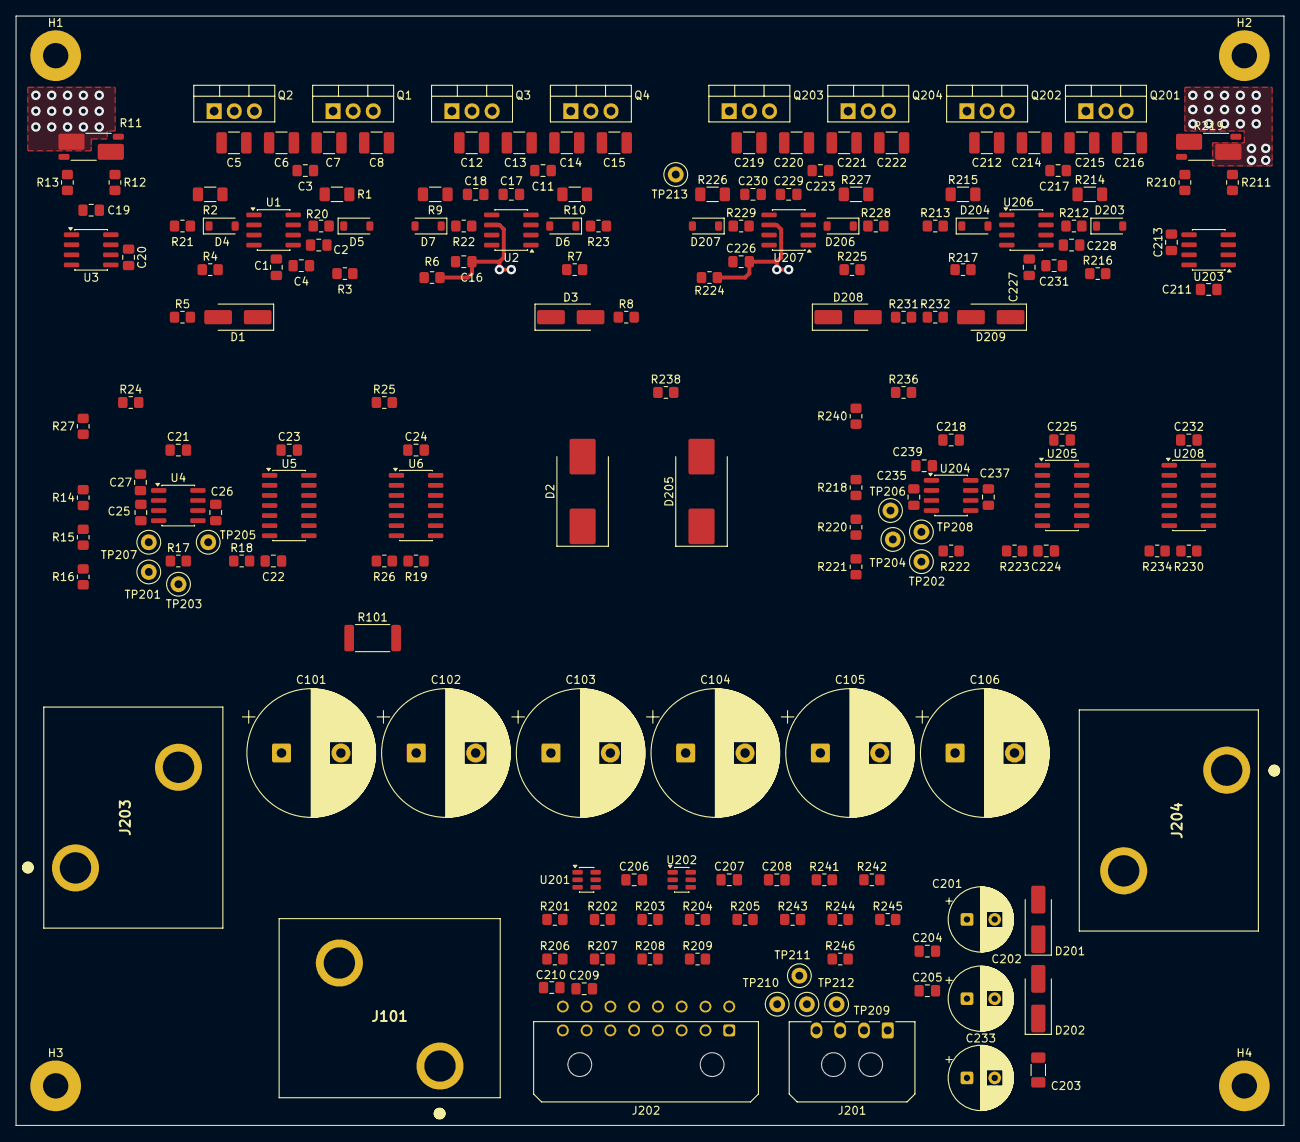
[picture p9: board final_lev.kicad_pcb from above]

Board: 4 copper layers, 160.0 x 140.0 mm, 197 parts (0 on the bottom side), 93 nets.

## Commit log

2026-08-13 Initial commit: levitation coil drive board, power_channel complete
    power_channel sheet finished and verified:
    - Full H-bridge (IRF100B201), 2x IR2184 gate drive with bootstrap
    - Asymmetric gate turn-off network (Crss 310 pF vs VGS(th) 2.0 V min)
    - In-line 1 mOhm 4-terminal Kelvin shunt + INA240A1 (20 mV/A, 1.65 V mid)
    - LM393 window comparator at +/-45 A into a set-dominant 74HC74 latch
    - Title block, 9 on-sheet annotation blocks, assumption register on the sheet
    Verification:
    - ERC 12 errors / 7 warnings, all traced to AUX_RAILS and IO_PROTECT not
    existing yet, plus the intentional SW_B/COIL_B naming
    - Update PCB from Schematic: 0 errors, 0 warnings (60 footprints, 39 nets)
    - Netlist cr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
    [bom_rev0.csv, final_lev.kicad_pcb, final_lev.kicad_sch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]
2026-08-14 Schematic complete: BUS, IO_PROTECT, dual power_channel instances, ERC clean
    [bom_rev0.csv, bus.kicad_sch, final_lev.kicad_sch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]
2026-08-14 Schematic complete: all sheets wired, ERC clean, netlist verified, cap ratings set
    [bom_rev0.csv, bus.kicad_sch, io_protect.kicad_sch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]
2026-08-14 All footprints assigned; fuse moved to harness; project footprint library added
    [bus.kicad_sch, io_protect.kicad_sch]
2026-08-14 clean rollback
    [final_lev.kicad_pcb]
2026-08-14 Adversarial review fixes: set-dominant latch, MCU enable, 3V3 hold-up, sense chain, 16-way connector
    [bus.kicad_sch, final_lev.kicad_pcb, final_lev.kicad_sch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]
2026-08-14 A14 modulation commitment (unipolar 3-level, 180 deg interleave); title blocks refreshed
    [bus.kicad_sch, final_lev.kicad_pcb, io_protect.kicad_sch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]
2026-08-14 Delta review fixes: POR timing, comparator supply, trip point, SD divider, Schmitt gate
    [final_lev.kicad_pcb, io_protect.kicad_sch, power_channel.kicad_sch]
2026-08-14 Interleave corrected 180->90 deg; U5 D pin to fail-safe; review addendum 2
    [power_channel.kicad_sch]
2026-08-14 Interleave 180->90 deg; U5 D pin to fail-safe; doc sweep for stale interleave refs
    [bus.kicad_sch, final_lev.kicad_pcb]
2026-08-21 PCB placement complete (160x140, 184 fp, 0 courtyard overlaps); layout phase docs + lay.py; handoff
    - Board resized 160x100 -> 160x140 after the courtyard-vs-pad-extent error
    - Full placement of all 184 footprints, DRC clean except unconnected
    - J203 moved inside the outline (x 107.0 -> 107.5), 0.450 mm margin
    - docs/20_layout_phase.md: floorplan, verified metrics, CH2 leg-swap analysis
    - docs/00_design_log.md: layout-phase entry incl. retraction of the
    'commutation loops trade values' claim (they are unchanged)
    - tools/lay.py: courtyard-accurate layout checker, rescued from /tmp
    - HANDOFF.md: remaining steps 1-3 with exact coordinates, transfer options
    CH2 leg A/B swap analysed and verif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
    [bus.kicad_sch, final_lev.kicad_pcb, final_lev.kicad_sch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]
2026-08-22 CH2 leg A/B swap applied: SW_A 55.6 -> 25.8 mm
    Leg B -30 mm X, leg A +30 mm X (42 footprints incl. bridge ceramics).
    Y and rotation unchanged on every part.
    Verified after the move:
    /CH2/SW_A 55.6 -> 25.8 mm
    /CH2/COIL_B2 97.0 -> 105.8 mm (accepted cost)
    courtyard overlaps 0
    commutation loops unchanged CH2 A 17.7 mm, CH2 B 16.7 mm
    FET thermal order C-H-C-H preserved on both channels
    heatsink shadow no intrusions
    all 42 coordinates exact against the target table
    Applied by direct file patch after three Move Exactly dialogs landed on
    wrong offsets (-32.08, -33.0, +29.5). KiCad closed for the patch; CRLF
    line endings preserved (59557, un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
    [final_lev.kicad_pcb]
2026-08-24 Stackup: fix copper 0.007 -> 0.07 mm (2 oz); decide 4 layers, 1 oz inner
    Copper weight was ten times too thin against the documented intent in
    14_power_channel_closeout.md. Nothing already done depended on it (KiCad
    does not compute ampacity) but it propagates into fab outputs. Board
    total 1.474 -> 1.600 mm; core left at 1.44.
    Layer count decided: 4 layers, 1 oz inner. Not the copper-loss argument
    (placed pours are already the IPC-2221 width for 30 A at dT=20 C, and an
    inner layer saves only 3.1 W of 9.30 W on a ~54 W board) but:
    - placement is identical either way, so choosing 4 now is free and
    choosing 2 and being wrong means a reroute
    - standard 1.6 mm 4L puts GND 0.2 mm under th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
    [final_lev.kicad_pcb]
2026-08-24 Windows portability: explicit UTF-8 in lay.py; PowerShell commands in HANDOFF
    lay.py opened the board file with open(PCB).read(), which uses the locale
    encoding on Windows (cp1252). Harmless today (the file is pure ASCII) but
    it would throw or corrupt the moment a micro/ohm/degree sign lands in a
    value field. Now explicit UTF-8 with errors='replace'.
    HANDOFF.md commands rewritten for Windows PowerShell:
    - no '&&' (unsupported in PowerShell 5.1) -- separate lines
    - 'py'/'python' rather than 'python3'
    - backslash paths; Remove-Item rather than rm
    Added a standing ground rule to the same effect.
2026-08-24 lay.py: stop running the pre-swap window check and the swap simulation
    The CH2 leg swap was applied in c9f1e50. Re-running the simulation on the
    swapped board shifts the legs a second time and reports 26 courtyard
    overlaps and parts off the outline, which reads as a broken board when
    nothing is wrong. Functions and SHIFT table kept as a record; not run.
2026-08-24 4-layer stackup, net class split, DRC rules, leg-A ceramic rotation
    [final_lev.kicad_pcb]
2026-08-27 README with H-bridge sketch; In1.Cu ground plane; library mismatch investigation
    [final_lev.kicad_pcb]
2026-08-27 Placement review: 16 parts moved, lay.py placement checks, coil pours to B.Cu
    [final_lev.kicad_pcb]
2026-08-28 Coil pours, test points, and a pad-rotation defect found by tooling
    Board:
    - 13 test points placed, grounds first so every signal point sits within 7.5 mm of its own ground return
    - All four 30 A coil pours drawn on B.Cu, single polygons, 10.7-11.0 mm at the narrowest cut
    - 34 vias transitioning the two A legs from the surface-mount shunts down to B.Cu, 15 at 2.0 A on CH1 and 19 at 1.58 A on CH2
    - The B legs need no vias: every pad carrying their current is through-hole
    Fixed:
    - 20 footprints had pads that did not follow their body rotation, 5 of them off by 90 degrees, which turns a 1.175 x 1.450 mm pad across the part instead of along it. Repaired by Update Footprints from Library
    -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
    [bus.kicad_sch, final_lev.kicad_pcb, io_protect.kicad_sch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]
2026-08-28 Complete the four coil nets: gate-drive stubs, VS vias, and drop the DRC rule that could not do its job
    - Six gate-drive connections routed on F.Cu: driver VS, bootstrap return and gate-source resistor on each channel
    - R6 and R224 rotated 180 so the coil pad faces the run, cutting each stub from 27.6 mm to 15.3 mm
    - Two vias per channel tying each stub to its B.Cu pour. The stub is front copper and the pour is back copper; a shared net name is not a connection
    - Removed the HV_POWER 10.7 mm track_width rule. It matched GND and every gate-drive net, so it demanded 10.7 mm for a bootstrap cap hop. Pour width is now verified by tools/pour_check.py, which can 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
    [final_lev.kicad_pcb]
2026-08-28 In2.Cu power plane, and A17 recomputed as a plane instead of a trace
    - +60V plane on In2.Cu with a finger to J101; reaches all 11 current-carrying pads through their own barrels, no vias in the power path
    - In2 split: GND below y=150 either side of the finger, so the IO connector signals on B.Cu have a ground reference rather than the bus
    - A17 corrected. The 28.0 mm figure applied the IPC-2221 trace formula to a plane; the same formula wants 146 mm on 1 oz inner, which is wider than the board. As a plane it is 0.54 squares, 0.46 mOhm end to end, 27 mV and 1.65 W at 60 A
    - lay.py zone overlap now rasterises outlines; bounding boxes reported two false collisions against the L-shaped plane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
    [final_lev.kicad_pcb]

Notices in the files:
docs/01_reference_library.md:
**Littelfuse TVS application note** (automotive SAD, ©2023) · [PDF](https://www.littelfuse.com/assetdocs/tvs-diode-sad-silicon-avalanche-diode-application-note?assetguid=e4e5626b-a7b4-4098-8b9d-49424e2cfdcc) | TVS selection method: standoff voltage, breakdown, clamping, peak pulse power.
